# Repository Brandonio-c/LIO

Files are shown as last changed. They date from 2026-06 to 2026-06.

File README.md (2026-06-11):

<p align="center">
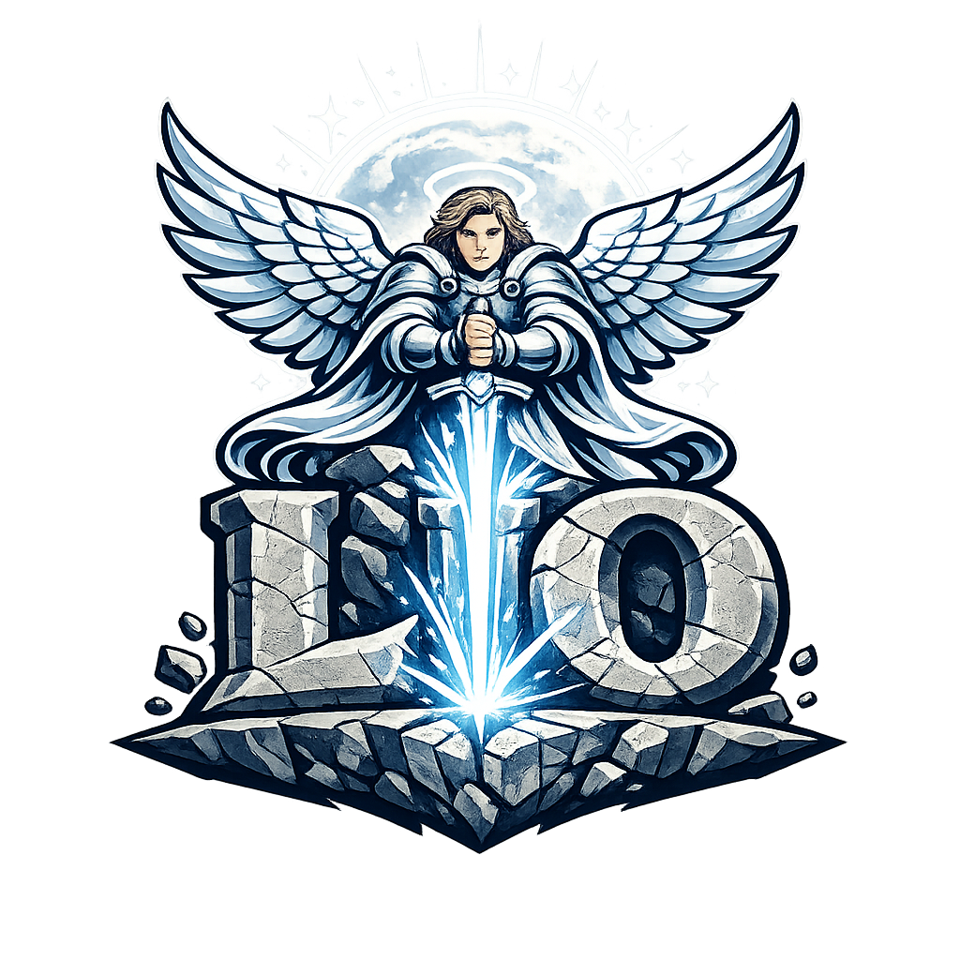
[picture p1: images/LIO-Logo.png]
LIO logo
  
</p>

**Lio** is an open hardware experiment to build a low-cost, 3D-printable multispectral diffuse-reflectance scanner for powdered food samples.

The project aims to collect repeatable optical reflectance data from controlled food powders and known mixtures using LED illumination, photodiode sensing, calibration references, and a motorized sample-height stage.

The core question LIO aims to answer is:

> Can a small, cheap, repeatable multispectral reflectance instrument produce enough signal to support useful closed-world food-powder classification or controlled-mixture experiments?

The honest answer is currently unknown. This repository documents the attempt.

---

## What Lio is trying to achieve

### Near-term goals

- Build a rigid, light-sealed optical chamber.
- Use one LED wavelength at a time to illuminate powdered samples.
- Measure reflected light using visible/NIR and SWIR detector paths.
- Normalize measurements using dark and PTFE white-reference readings.
- Create repeatable reflectance vectors for each sample.
- Validate mechanical repeatability before training any model.
- Test simple controlled mixtures before attempting complex packaged foods.

### Long-term goals

- Build a dataset of calibrated reflectance scans from known powders and mixtures.
- Compare simple models such as PCA, logistic regression, SVM, and PLS regression before trying neural networks.
- Evaluate whether additional SWIR wavelengths improve separability.
- Develop a closed-world composition-hypothesis workflow.
- Eventually detect whether unknown samples are optically consistent with trained known mixtures.

## Measurement concept

Lio uses **multispectral diffuse reflectance**.

A powdered sample sits in a controlled cup inside a dark, black-lined chamber. LEDs illuminate the sample one wavelength at a time. A detector measures reflected light from the sample. Each wavelength produces one channel value.

A scan sequence looks like this:

1. Record dark readings with all LEDs off.
2. Record white-reference readings using a PTFE reference insert.
3. Record sample readings using the food powder.
4. Normalize each channel:

```text
R_i = (S_i - D_i) / (W_i - D_i)
```

Where:

```text
R_i = normalized reflectance for wavelength i
S_i = sample reading
D_i = dark reading
W_i = white-reference reading
```

Optional absorbance-like transformation:

```text
A_i = -log10(R_i)
```

The output of one scan is a reflectance vector such as:

```text
[red, green, blue, 400, 890, 1020, 1200, 1300, 1450, 1550, 1650, 1760]
```

Exact channels depend on which LED modules are installed.

---

## Optical design

The optical system is built around a fixed top optical head and a moving bottom sample platform.

### Fixed optical section

- Top detector cap.
- Detector snout / aperture tube.
- LED ring with removable LED cartridges.
- Outer optical tube.
- Removable black flocked inner sleeve.
- Internal baffle rings.
- Bottom fixed collar / upper telescoping receiver.

### Moving sample section

- Moving sample platform.
- Powder sample cup.
- PTFE reference holder.
- Dark reference plug.
- Moving telescoping skirt / lower light-seal sleeve.

### Telescoping light-seal concept

The fixed optical chamber does not move. The sample platform moves up and down on a motorized Z-stage. A lower moving sleeve overlaps with an upper fixed collar so the optical path remains dark while the sample height changes.

```text
fixed optical tube
    ↓
bottom fixed collar / upper receiver
    ↓ overlaps with
moving telescoping skirt
    ↓ attached to
moving sample platform
    ↓ driven by
M6 threaded rod + 28BYJ motor
```

This is the physical mechanism referred to as the Lio telescoping focusing channel. It is not a lens. It is a light-sealed adjustable sample-height shroud.

---

## Mechanical architecture

The current mechanical architecture is a PETG 3D-printed tower with metal guide hardware.

### Motion system

- 28BYJ-48 5 V stepper motor.
- ULN2003 stepper driver board.
- M6 threaded rod as the vertical drive screw.
- M6 nut trapped in the moving platform.
- Two 8 mm guide rods.
- LM8UU linear bearings.
- Top guide bridge to keep rods parallel.
- Bottom motor base to hold rods, motor, screw, and endstop.
- Endstop switches for homing/safety.

### Coordinate logic

The mechanical drive axis and sample/optical axis are intentionally different:

```text
M6 drive axis:       X = 0, Y = 0
left guide rod:      X = -45, Y = 0
right guide rod:     X = +45, Y = 0
sample/optical axis: X = 0, Y = +35
```

The sample cup is offset forward so the M6 threaded rod does not pass through the sample.

The fixed tower frame holds the optical tube over the sample axis, not over the M6 drive axis.

---

## Electronics architecture

### Control and acquisition

- Arduino Nano or compatible controller
- ADS1115 16-bit I2C ADC modules
- One-LED-at-a-time sequencing
- Dark / white / sample scan workflow

### Detector paths

- OPT101 module for visible and shorter NIR channels
- InGaAs photodiode with an OPA381 transimpedance amplifier for SWIR channels

### LED control

- Individually addressable LED channels
- MOSFET or LED-driver switching
- A single channel active at any moment
- Optional current control / PWM dimming once baseline stability is established

### Motor control

- 28BYJ-48 stepper motor
- ULN2003 driver board
- External 5 V supply or power bank for motor power
- Shared ground between the motor supply and the Arduino

---

## CAD file set

The CAD is authored in OpenSCAD. Most files generate printable STL parts; one file is a non-printing assembly preview.

```text
01_lio_fit_tests.scad
02_lio_outer_tube.scad
03_lio_inner_sleeve.scad
04_lio_baffle_rings.scad
05_lio_detector_cap.scad
06_lio_led_ring.scad
07_lio_led_cartridges.scad
08_lio_bottom_collar.scad
09_lio_motor_base.scad
10_lio_top_guide_bridge.scad
11_lio_moving_platform.scad
12_lio_moving_telescoping_skirt.scad
13_lio_sample_accessories.scad
14_lio_electronics_tray.scad
15_lio_fixed_tower_frame.scad
16_lio_assembly_preview.scad
```

### 01 — Fit tests

Small validation prints for LM8UU bearing bores, M6 nut traps, M3 heat-set inserts, and 8 mm rod spacing. Print these before committing to large mechanical parts.

### 02 — Outer optical tube

The main fixed optical chamber body: 80 mm outer tube, 60 mm inner bore, top and bottom flanges, M3 insert bosses, an inner-sleeve alignment feature, and baffle-retaining ledges.

### 03 — Removable inner sleeve

A thin PETG cylinder that carries the black telescope flocking and lifts out for cleaning or optical adjustment.

### 04 — Baffle rings

Internal annular baffles that suppress glancing wall reflections and stray light.

### 05 — Detector cap

The top detector cap, with a PCB pocket, aperture, detector snout, and a wire-exit light-trap feature.

### 06 — LED ring

A 16-slot modular LED-ring body that accepts removable LED cartridges rather than fixing LED types permanently.

### 07 — LED cartridges

Wedge/cartridge inserts sized for 3 mm LEDs, 5 mm LEDs, SMD LEDs, and TO-can / metal-can emitters.

### 08 — Bottom collar / upper receiver

The fixed half of the telescoping light seal, mounted beneath the optical tube to receive and overlap the moving skirt.

### 09 — Motor base

The base of the Z-stage: 28BYJ motor mount, lower 8 mm guide-rod sockets, M6/coupler clearance, bottom endstop area, and an optional ULN2003 mount region.

### 10 — Top guide bridge

Anchors the top ends of the guide rods and provides upper M6 clearance and support.

### 11 — Moving platform

The sample carriage: LM8UU bearing housings, an M6 nut trap, a sample-cup pocket, an endstop flag, a height pointer, and mounting holes for the telescoping skirt.

### 12 — Moving telescoping skirt

The moving lower half of the telescoping light seal, mounted to the platform and overlapping the fixed receiver.

### 13 — Sample accessories

A batch of sample-prep and calibration parts: powder sample cup, PTFE reference holder, dark reference plug, and a leveling ring / scraper guide.

### 14 — Electronics tray

An open service tray for the Arduino, ADS1115 modules, ULN2003 board, USB pigtail strain relief, wire clips, and an LED cable comb.

### 15 — Fixed tower frame

The structural bridge between the stationary optical chamber and the motorized Z-stage. It holds the fixed optical tube/collar above the offset sample axis and turns the telescoping seal into a mechanically constrained assembly.

### 16 — Assembly preview

A non-printing OpenSCAD file that visualizes the full assembly. A `stage_z` parameter previews the platform at different heights. This file is for visualization only and is not sliced or printed.

---

## Recommended printing order

Mechanical geometry and fit tolerances take priority over the cosmetic optical shell, so print in this order:

```text
01 fit tests
09 motor base
10 top guide bridge
11 moving platform
12 moving telescoping skirt
15 fixed tower frame
08 bottom fixed collar
02 outer optical tube
03 inner sleeve
04 baffle rings
05 detector cap
06 LED ring
07 LED cartridges
13 sample accessories
14 electronics tray
16 assembly preview (visualization only)
```

---

## Print settings

Baseline settings for PETG on the Ender-3 V3 SE:

```text
Nozzle: 235–245 °C
Bed: 75–85 °C
Layer height: 0.20 mm
Walls: 4 for structural parts
Infill: 35–45% for mechanical parts
Supports: OFF where geometry is supportless
Brim: ON for tall/thin parts
First layer speed: 15–20 mm/s
Fan: low/off for first layers, then moderate
Bed prep: clean plate + thin glue-stick layer
```

Tall, thin parts such as the inner sleeve and baffle rings benefit from additional brim, sacrificial carrier strips, or shorter test prints.

---

## Data collection workflow

A complete scan session follows this sequence:

1. Home the Z-stage.
2. Set a known sample height.
3. Record a dark scan with LEDs off.
4. Insert the PTFE reference holder.
5. Record a white-reference scan.
6. Insert the sample cup.
7. Fire each LED one at a time.
8. Record detector readings.
9. Normalize using dark/white calibration.
10. Save raw and normalized data with metadata.

Each record carries metadata for full traceability:

```text
sample ID
batch ID
operator
timestamp
sample mass
sample cup depth
grind/sieve method
LED channel
LED current/PWM
detector used
TIA gain setting
ADC gain setting
sample height
temperature/humidity if available
white reference ID
firmware version
CAD revision
```

---

## Validation plan

Repeatability is verified before any modeling begins.

### Mechanical repeatability

- The Z-stage homes consistently.
- The platform moves smoothly without binding.
- The moving skirt overlaps the fixed receiver across all usable heights.
- The sample cup stays centered under the optical axis.

### Optical repeatability

- Dark readings hold steady over time.
- PTFE reference readings repeat across insert/remove cycles.
- A given powder yields repeatable normalized reflectance vectors.
- The chamber, wire exits, and telescoping sleeve stay light-tight.

### Dataset integrity

- Controlled binary mixtures precede complex packaged foods.
- Validation uses held-out batches and days.
- Repeated scans of the same physical sample are kept together rather than split across train and test sets.

---

## Modeling plan

Modeling starts with interpretable methods and adds complexity only as the data justifies it:

- PCA for visualization.
- Logistic regression, SVM, and random forest for classification.
- PLS regression for controlled concentration estimation.
- Neural networks introduced once enough independent, repeatable data exists to support them.

The first concrete targets are:

```text
Can Lio distinguish known powder classes under controlled preparation?
```

and:

```text
Can Lio estimate the percentage of one ingredient in a controlled binary mixture?
```

---

## Repository structure

```text
lio/
├── README.md
├── cad/
│   ├── 01_lio_fit_tests.scad
│   ├── 02_lio_outer_tube.scad
│   ├── 03_lio_inner_sleeve.scad
│   ├── 04_lio_baffle_rings.scad
│   ├── 05_lio_detector_cap.scad
│   ├── 06_lio_led_ring.scad
│   ├── 07_lio_led_cartridges.scad
│   ├── 08_lio_bottom_collar.scad
│   ├── 09_lio_motor_base.scad
│   ├── 10_lio_top_guide_bridge.scad
│   ├── 11_lio_moving_platform.scad
│   ├── 12_lio_moving_telescoping_skirt.scad
│   ├── 13_lio_sample_accessories.scad
│   ├── 14_lio_electronics_tray.scad
│   ├── 15_lio_fixed_tower_frame.scad
│   └── 16_lio_assembly_preview.scad
├── stl/
├── gcode/
├── firmware/
├── electronics/
├── data/
│   ├── raw/
│   ├── processed/
│   └── metadata/
├── notebooks/
├── docs/
└── photos/
```

---

## Current status

Lio is in early mechanical prototyping.

- Hardware components have been sourced.
- 3D-printer setup is underway.
- OpenSCAD files are evolving iteratively.
- The design now includes a fixed tower frame and assembly preview, which add the assembly constraints the original part list lacked.
- Current focus is mechanical fit and light sealing.
- Electronics and data collection follow once the physical platform is stable.

---

## Safety and operating notes

Lio is an experimental research prototype intended for controlled laboratory and educational use.

LEDs across the visible, UV, NIR, and SWIR ranges can deliver significant optical power, and some wavelengths are invisible while still being energetic. Handle the optics with appropriate care: avoid looking directly into LEDs, use current limiting, keep the optical path enclosed, and treat unknown high-power emitters with caution.

Results from Lio are research data. Keep them within the closed-world experimental context the instrument is built for.

---

## References

- Near-infrared spectroscopy in food quality assurance (review): https://www.mdpi.com/3022876
- NIST PTFE 45°/0° reflectance reference work: https://nvlpubs.nist.gov/nistpubs/jres/104/2/html/nad-k/nad.htm
- OpenSCAD documentation: https://openscad.org/documentation.html
- Creality Ender-3 V3 SE specifications: https://store.creality.com/products/ender-3-v3-se-3d-printer
- STL file format reference: https://www.xometry.com/resources/3d-printing/stl-file-format/

---

## License

A license has not yet been selected. Before the project opens to outside contributions, a license will be chosen deliberately. Candidate options include:

- MIT License for code
- CERN Open Hardware License for hardware/CAD
- Creative Commons license for documentation

---

## Project philosophy

Lio is an exercise in disciplined instrument design: build a controlled, repeatable measurement platform, collect clean data, and map out exactly what low-cost multispectral reflectance can do for closed-world food analysis. The work centers on repeatable measurements, well-characterized limits, and a clear, incremental path from mechanical validation to controlled-mixture discrimination and narrow classification.D_i = dark reading
W_i = white-reference reading
```

An optional absorbance-like transform is also available:

```text
A_i = -log10(R_i)
```

Each scan produces a reflectance vector, for example:

```text
[red, green, blue, 400, 890, 1020, 1200, 1300, 1450, 1550, 1650, 1760]
```

The exact channel set depends on which LED modules are installed.

---

## Optical design

The optical system pairs a fixed top optical head with a moving bottom sample platform.

### Fixed optical section

- Top detector cap
- Detector snout / aperture tube
- LED ring with removable LED cartridges
- Outer optical tube
- Removable black-flocked inner sleeve
- Internal baffle rings
- Bottom fixed collar / upper telescoping receiver

### Moving sample section

- Moving sample platform
- Powder sample cup
- PTFE reference holder
- Dark reference plug
- Moving telescoping skirt / lower light-seal sleeve

### Telescoping light seal

The optical chamber stays stationary while the sample platform travels vertically on a motorized Z-stage. A lower moving sleeve overlaps a fixed upper collar, keeping the optical path sealed against ambient light across the full range of sample heights.

```text
fixed optical tube
    ↓
bottom fixed collar / upper receiver
    ↓ overlaps with
moving telescoping skirt
    ↓ attached to
moving sample platform
    ↓ driven by
M6 threaded rod + 28BYJ motor
```

This mechanism is referred to as the Lio telescoping focusing channel: a light-sealed, adjustable sample-height shroud that maintains a dark optical path as the sample height changes.

---

## Mechanical architecture

The mechanical platform is a PETG 3D-printed tower built around metal guide hardware.

### Motion system

- 28BYJ-48 5 V stepper motor
- ULN2003 stepper driver board
- M6 threaded rod as the vertical drive screw
- M6 nut captured in the moving platform
- Two 8 mm guide rods
- LM8UU linear bearings
- Top guide bridge to keep the rods parallel
- Bottom motor base holding the rods, motor, screw, and endstop
- Endstop switches for homing and travel limits

### Coordinate logic

The mechanical drive axis and the sample/optical axis are intentionally separated:

```text
M6 drive axis:       X = 0, Y = 0
left guide rod:      X = -45, Y = 0
right guide rod:     X = +45, Y = 0
sample/optical axis: X = 0, Y = +35
```

Offsetting the sample cup forward keeps the M6 threaded rod clear of the sample. The fixed tower frame positions the optical tube direct# Lio

**Lio** is an open-hardware research instrument: a low-cost, 3D-printable multispectral diffuse-reflectance scanner for powdered food samples.

We are building a benchtop optical instrument that shines light through a sequence of individual LED wavelengths onto a prepared food powder, measures how much light each wavelength reflects back, and turns that into a calibrated spectral signature for the sample. By collecting these signatures across many known powders and controlled mixtures, we can train models that recognize what a sample is, or estimate how much of one ingredient is present in a blend. The entire instrument — optical chamber, motorized sample stage, electronics housing — is 3D-printable and built from inexpensive, widely available parts, so the whole design can be reproduced on a hobbyist printer for a fraction of the cost of a commercial spectrometer.

The work spans three layers that come together into a single platform:

- **Hardware** — a rigid, light-sealed optical chamber paired with a motorized Z-stage that raises and lowers the sample while keeping the optical path dark. LEDs illuminate one wavelength at a time; visible/NIR and SWIR detectors capture the reflected light.
- **Acquisition** — a calibrated scan workflow that normalizes every reading against dark and white references, producing repeatable reflectance vectors with full metadata for traceability.
- **Modeling** — a data pipeline that starts with interpretable methods (PCA, regression, SVM, PLS) to classify known powders and estimate controlled-mixture ratios, expanding toward more complex models as the dataset grows.

The scope is deliberately focused:

> A repeatable, closed-world optical data-collection platform for evaluating whether low-cost multispectral reflectance can classify known powdered foods and estimate changes in controlled mixtures.

---

## Motivation

Visible/NIR/SWIR spectroscopy is a well-established approach to food analysis. Near-infrared methods are widely deployed for rapid quality control, origin and authenticity screening, and broad compositional analysis, typically paired with chemometric calibration models. These techniques are indirect and calibration-driven by nature: the instrument measures reflected light, and a trained model maps that signal to a property of interest.

Lio brings that idea down to a hobbyist-accessible price point by replacing a full commercial spectrometer with a set of discrete, individually addressable LEDs. The central research question is straightforward:

> Can a small, inexpensive, repeatable multispectral reflectance instrument produce enough usable signal to support closed-world food-powder classification or controlled-mixture estimation?

This repository documents the design, build, and experimental program developed to answer that question.

---

## Objectives

### Near-term

- Build a rigid, light-sealed optical chamber.
- Illuminate powdered samples one LED wavelength at a time.
- Measure reflected light across visible/NIR and SWIR detector paths.
- Normalize every measurement against dark and PTFE white-reference readings.
- Produce repeatable reflectance vectors for each sample.
- Establish mechanical repeatability as a precondition for any modeling.
- Characterize simple controlled mixtures before moving to complex packaged foods.

### Long-term

- Assemble a calibrated dataset of reflectance scans from known powders and mixtures.
- Benchmark interpretable models (PCA, logistic regression, SVM, PLS regression) before exploring neural networks.
- Quantify how additional SWIR wavelengths affect class separability.
- Develop a closed-world composition-hypothesis workflow.
- Determine whether unknown samples are optically consistent with trained known mixtures.

---

## Scope

Lio is a research-grade instrument for controlled, closed-world experiments. It is purpose-built to:

- Acquire calibrated reflectance data from prepared powdered samples.
- Discriminate among a known, trained set of powder classes.
- Estimate mixture ratios within controlled binary systems.

Its design priority is measurement integrity: prove repeatability first, then controlled-mixture discrimination, then narrow closed-world classification. The instrument is intended for experimental and educational use rather than food-safety, medical, or regulatory applications.

---

## Measurement principle

Lio operates on **multispectral diffuse reflectance**.

A powdered sample sits in a controlled cup inside a dark, black-lined chamber. LEDs illuminate the sample one wavelength at a time, and a detector measures the diffusely reflected light. Each wavelength contributes one channel to the resulting spectral vector.

A scan sequence proceeds as follows:

1. Record dark readings with all LEDs off.
2. Record white-reference readings using a PTFE reference insert.
3. Record sample readings from the food powder.
4. Normalize each channel:

```text
R_i = (S_i - D_i) / (W_i - D_i)
```

Where:

```text
R_i = normalized reflectance for wavelength i
S_i = sample reading
D_i = dark reading
W_i = white

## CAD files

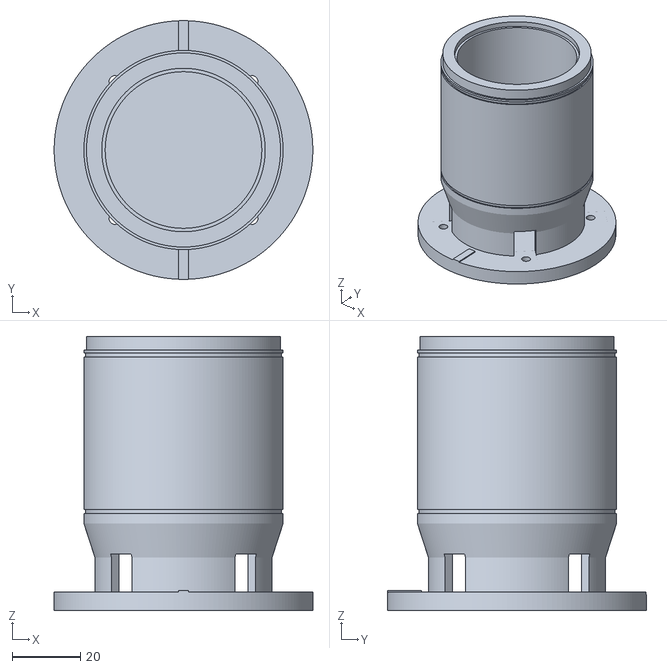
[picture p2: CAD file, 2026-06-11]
CAD/013-LIO-3D-print_moving_telescoping_skirt_v01.stl
76.0 x 76.0 x 80.5

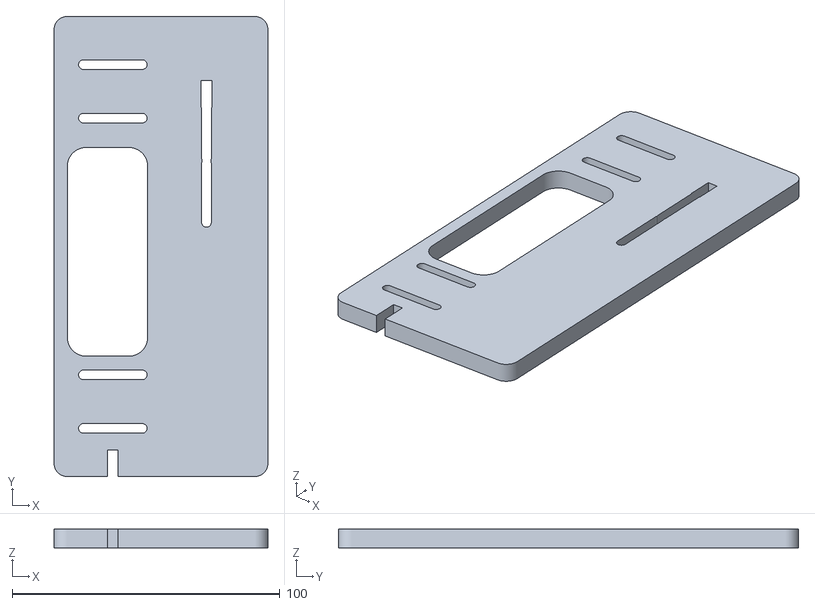
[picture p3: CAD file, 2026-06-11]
CAD/15_lio_fixed_tower_frame_v01.stl
80.0 x 172.0 x 7.00

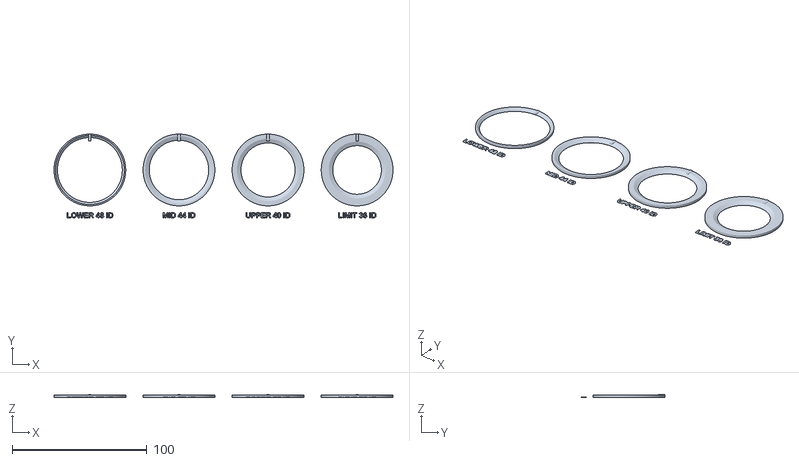
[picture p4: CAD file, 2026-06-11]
CAD/005-LIO-3D-print_baffle_ring_set_v01.stl
251.2 x 62.1 x 2.40

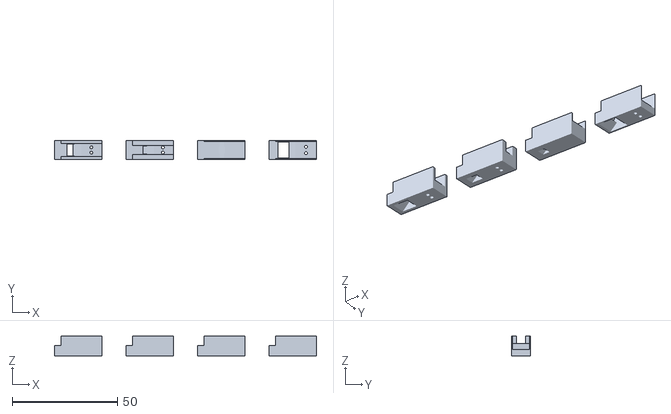
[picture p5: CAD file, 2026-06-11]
CAD/008-LIO-3D-print_led_cartridge_wedge_set_v02_SUPPORTLESS.stl
124.5 x 8.80 x 9.40

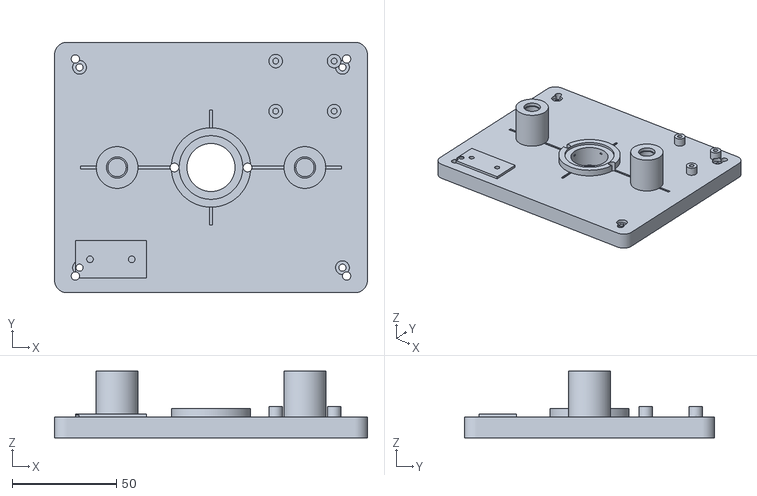
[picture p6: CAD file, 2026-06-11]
CAD/010-LIO-3D-print_motor_base_v01.stl
150.0 x 120.0 x 32.0

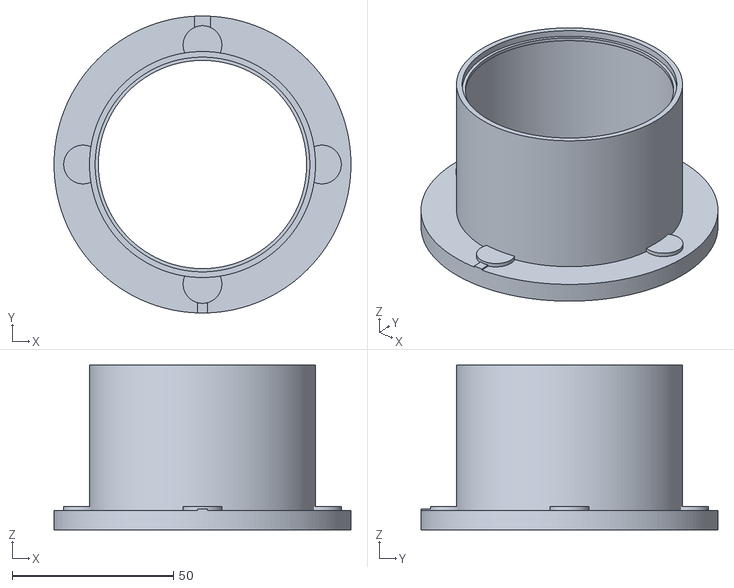
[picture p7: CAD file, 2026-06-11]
CAD/009-LIO-3D-print_bottom_fixed_collar_v01.stl
92.0 x 92.0 x 51.0

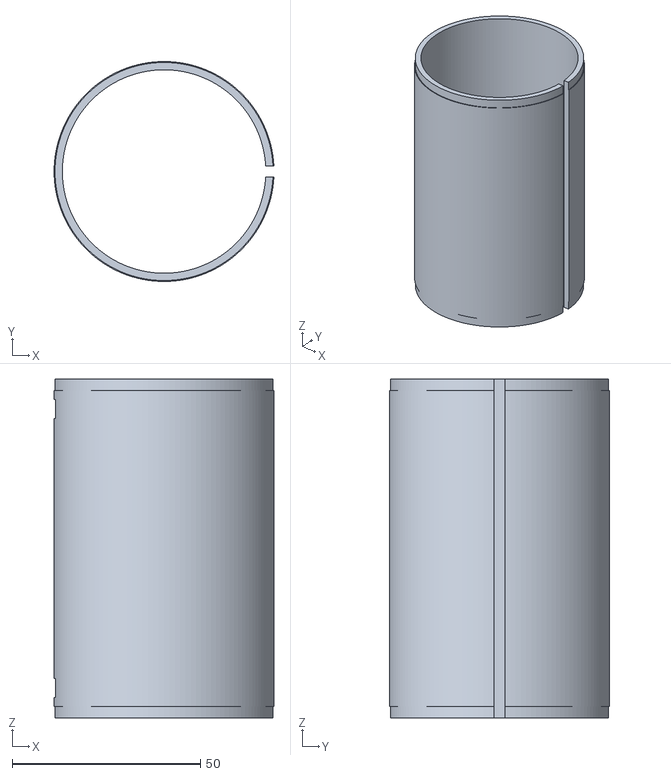
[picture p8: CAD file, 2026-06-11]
CAD/004-LIO-3D-print_inner_sleeve_v01.stl
58.4 x 58.4 x 90.0

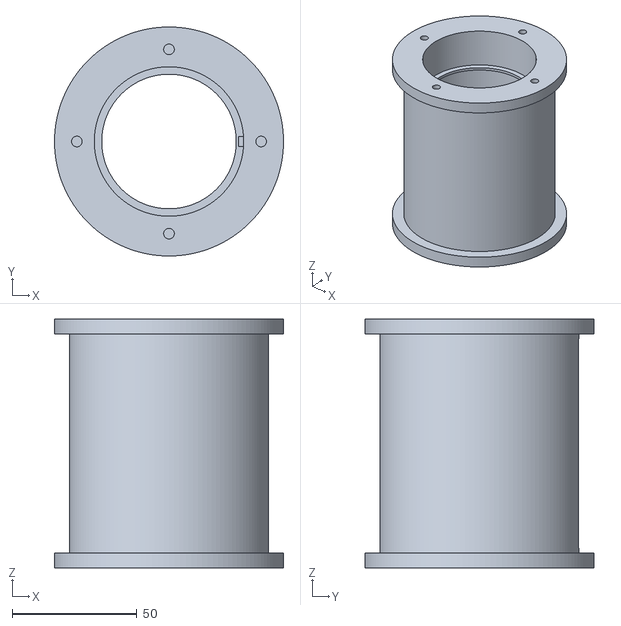
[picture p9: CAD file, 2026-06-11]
CAD/003-LIO-3D-print_outer_optical_tube_v01.stl
92.0 x 92.0 x 100.0

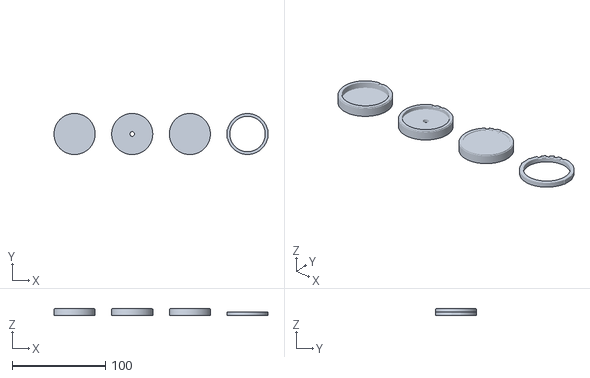
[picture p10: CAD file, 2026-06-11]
CAD/014-LIO-3D-print_sample_accessory_batch_v01.stl
230.1 x 44.2 x 8.00

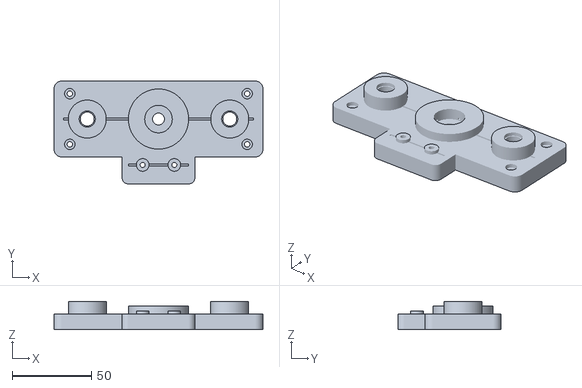
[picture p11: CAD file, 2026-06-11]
CAD/011-LIO-3D-print_top_guide_bridge_v02.stl
132.0 x 65.0 x 18.0

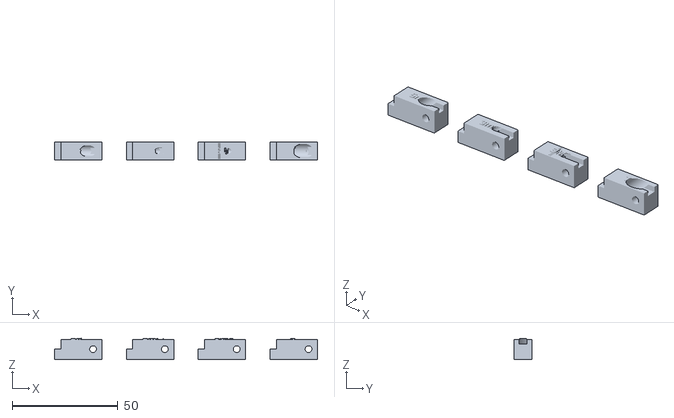
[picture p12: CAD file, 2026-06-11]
CAD/008-LIO-3D-print_led_cartridge_wedge_set_v01.stl
124.5 x 8.60 x 10.1

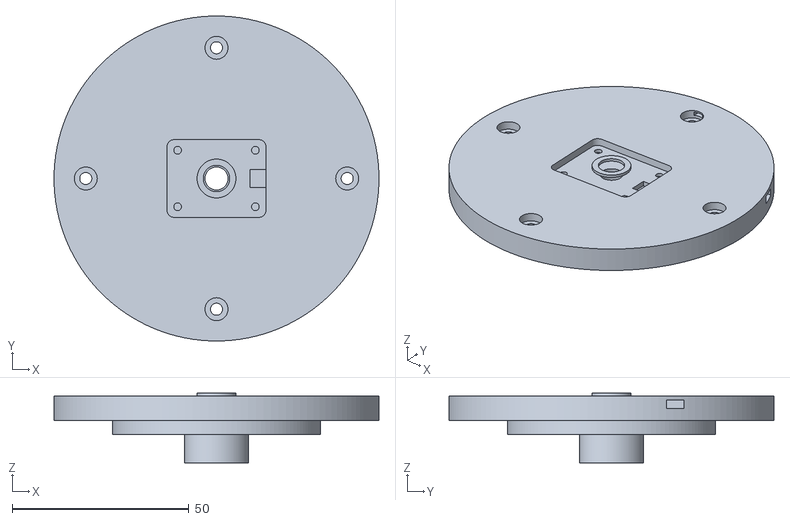
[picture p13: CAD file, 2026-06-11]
CAD/006-LIO-3D-print_detector_cap_OPT101_v01.stl
92.0 x 92.0 x 19.8

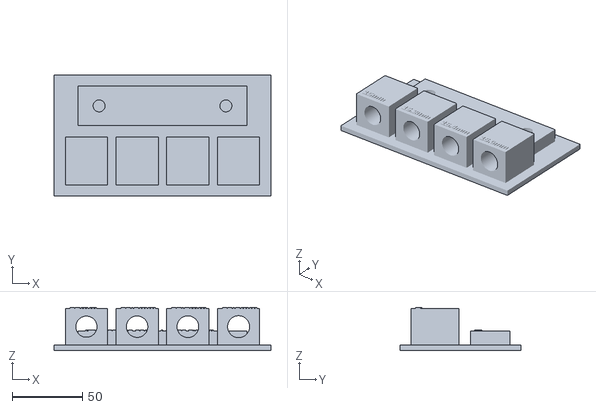
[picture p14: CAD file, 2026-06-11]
CAD/001-LIO-3D-print_test-parts.stl
154.0 x 86.0 x 30.7

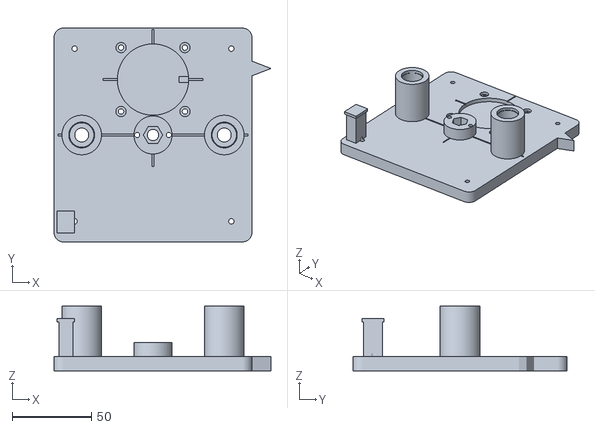
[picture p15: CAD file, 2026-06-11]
CAD/012-LIO-3D-print_moving_sample_platform_v01.stl
137.0 x 135.0 x 41.0

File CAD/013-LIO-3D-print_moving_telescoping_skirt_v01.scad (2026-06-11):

// Lio v0.1 — Moving Telescoping Skirt / Lower Light-Seal Sleeve
// Units: millimeters
//
// This part integrates:
// - moving half of telescoping optical shroud
// - sample cup opening / optical path opening
// - flocking carrier sleeve
// - mounting flange to moving sample platform
//
// Physical role:
// - Mounts to the moving sample platform around the sample cup.
// - Moves up/down with the sample.
// - Slides into / overlaps with the fixed bottom collar receiver.
// - Preserves a dark optical path while the Z-stage moves.
//
// PRINT ORIENTATION:
// - Flange flat on bed at Z=0.
// - Sleeve prints upward.
// - Supports OFF.
//
// Material:
// - Black PETG recommended.
//
// Suggested print settings:
// - 0.20 mm layer height
// - 3–4 walls
// - 25–35% infill
// - supports OFF
// - brim optional

$fn = 160;
eps = 0.05;

// ---------------------------------------------------------
// Main skirt geometry
// ---------------------------------------------------------

// Main upper sleeve outer diameter.
// This slides into the fixed bottom collar receiver.
// Fixed collar receiver ID was about 64.5 mm,
// so 58.5 mm gives generous clearance for flocking and imperfect rods.
sleeve_od = 58.5;

// Inner optical/sample opening.
// 44–50 mm recommended.
// Use 46 mm as a sane v0.1 balance.
sleeve_id = 46.0;

// Total sleeve region above flange is:
// lower neck + tapered transition + main sleeve
lower_neck_od = 52.0;      // clears M3 mount holes better than full 58.5 OD
lower_neck_h  = 10.0;

transition_h = 10.0;       // tapered section from lower neck to full sleeve OD
main_sleeve_h = 55.0;      // straight upper sleeve height

total_sleeve_h = lower_neck_h + transition_h + main_sleeve_h;

// ---------------------------------------------------------
// Mounting flange geometry
// ---------------------------------------------------------

flange_od = 76.0;
flange_t  = 5.5;

// Must match moving platform skirt_mount_bcd = 57 from Print 12.
mount_bcd = 57.0;
mount_r = mount_bcd / 2;

m3_clearance_d = 3.4;

// No screw-head recess by default.
// Recesses would collide with the lower neck at this compact bolt circle.
enable_screw_head_recess = false;
m3_head_recess_d = 6.5;
m3_head_recess_depth = 2.0;

// Screw access notches cut into the lower neck so you can physically
// reach the M3 screws even though the sleeve is close to the bolt circle.
enable_screw_access_notches = true;
screw_access_radial_len = 12.0;
screw_access_tangent_w = 8.5;
screw_access_h = lower_neck_h + 1.0;

// ---------------------------------------------------------
// Flocking / liner features
// ---------------------------------------------------------

// Outer shallow grooves help locate/catch the edge of external flocking,
// if you decide to flock the outside of the moving skirt.
// Keep these shallow so the skirt remains strong.
enable_flocking_edge_grooves = true;
flocking_groove_depth = 0.5;
flocking_groove_h = 1.2;

// Position grooves near lower and upper areas of the main sleeve.
flocking_lower_groove_z = flange_t + lower_neck_h + transition_h + 3;
flocking_upper_groove_z = flange_t + total_sleeve_h - 6;

// ---------------------------------------------------------
// Lead-in / anti-scrape features
// ---------------------------------------------------------

// Slightly reduce OD at very top so it enters the fixed receiver more easily.
enable_top_leadin = true;
top_leadin_h = 4.0;
top_leadin_od_reduction = 1.5;

// Slight inner mouth bevel/relief.
// This is a straight relief, not a true curved chamfer.
enable_inner_mouth_relief = true;
inner_mouth_relief_d = sleeve_id + 2.0;
inner_mouth_relief_h = 2.0;

// ---------------------------------------------------------
// Optional alignment mark
// ---------------------------------------------------------

enable_alignment_mark = true;
alignment_mark_w = 3.0;
alignment_mark_l = 9.0;
alignment_mark_depth = 0.8;

// ---------------------------------------------------------
// Helper modules
// ---------------------------------------------------------

module ring(od, id, h) {
    difference() {
        cylinder(d = od, h = h);
        translate([0, 0, -1])
            cylinder(d = id, h = h + 2);
    }
}

module tapered_ring(od1, od2, id, h) {
    difference() {
        cylinder(d1 = od1, d2 = od2, h = h);
        translate([0, 0, -1])
            cylinder(d = id, h = h + 2);
    }
}

module mount_holes_cut() {
    for (a = [45, 135, 225, 315]) {
        rotate([0, 0, a])
        translate([mount_r, 0, -1]) {
            cylinder(d = m3_clearance_d, h = flange_t + 2);

            if (enable_screw_head_recess) {
                translate([0, 0, flange_t - m3_head_recess_depth])
                    cylinder(d = m3_head_recess_d,
                             h = m3_head_recess_depth + 1);
            }
        }
    }
}

module screw_access_notches_cut() {
    if (enable_screw_access_notches) {
        for (a = [45, 135, 225, 315]) {
            rotate([0, 0, a])
            translate([
                mount_r,
                0,
                flange_t + screw_access_h/2
            ])
                cube([
                    screw_access_radial_len,
                    screw_access_tangent_w,
                    screw_access_h + 2*eps
                ], center = true);
        }
    }
}

module flocking_edge_groove_cut(zpos) {
    if (enable_flocking_edge_grooves) {
        // Shallow external annular groove.
        // Cuts only the outside surface of the upper sleeve.
        translate([0, 0, zpos])
        difference() {
            cylinder(d = sleeve_od + 2, h = flocking_groove_h);
            translate([0, 0, -eps])
                cylinder(d = sleeve_od - 2*flocking_groove_depth,
                         h = flocking_groove_h + 2*eps);
        }
    }
}

module top_leadin_cut() {
    if (enable_top_leadin) {
        // Remove a shallow outer band at the very top,
        // reducing OD slightly for easier entry into fixed collar receiver.
        translate([0, 0, flange_t + total_sleeve_h - top_leadin_h])
        difference() {
            cylinder(d = sleeve_od + 2, h = top_leadin_h + eps);
            translate([0, 0, -eps])
                cylinder(d = sleeve_od - top_leadin_od_reduction,
                         h = top_leadin_h + 2*eps);
        }
    }
}

module inner_mouth_relief_cuts() {
    if (enable_inner_mouth_relief) {
        // Relief at top inner opening.
        translate([0, 0, flange_t + total_sleeve_h - inner_mouth_relief_h])
            cylinder(d = inner_mouth_relief_d,
                     h = inner_mouth_relief_h + eps);

        // Relief at bottom inner opening / flange entry.
        translate([0, 0, -eps])
            cylinder(d = inner_mouth_relief_d,
                     h = inner_mouth_relief_h + eps);
    }
}

module alignment_mark_cut() {
    if (enable_alignment_mark) {
        // Shallow notch on flange outer edge at +Y.
        translate([
            0,
            flange_od/2 - alignment_mark_l/2,
            flange_t - alignment_mark_depth/2 + eps
        ])
            cube([
                alignment_mark_w,
                alignment_mark_l,
                alignment_mark_depth + 2*eps
            ], center = true);
    }
}

// ---------------------------------------------------------
// Main model
// ---------------------------------------------------------

difference() {

    union() {

        // Bottom mounting flange.
        cylinder(d = flange_od, h = flange_t);

        // Lower neck. Smaller OD clears mounting screws.
        translate([0, 0, flange_t])
            ring(lower_neck_od, sleeve_id, lower_neck_h);

        // Sloped transition out to full telescoping sleeve OD.
        // Supportless because it is a gradual outward taper.
        translate([0, 0, flange_t + lower_neck_h])
            tapered_ring(
                od1 = lower_neck_od,
                od2 = sleeve_od,
                id = sleeve_id,
                h = transition_h
            );

        // Main moving telescoping sleeve.
        translate([0, 0, flange_t + lower_neck_h + transition_h])
            ring(sleeve_od, sleeve_id, main_sleeve_h);
    }

    // Mounting holes matching Print 12 moving platform.
    mount_holes_cut();

    // Access notches around lower neck for screw access.
    screw_access_notches_cut();

    // External flocking edge grooves.
    flocking_edge_groove_cut(flocking_lower_groove_z);
    flocking_edge_groove_cut(flocking_upper_groove_z);

    // Top lead-in relief.
    top_leadin_cut();

    // Inner mouth reliefs.
    inner_mouth_relief_cuts();

    // Alignment notch.
    alignment_mark_cut();
}

// ---------------------------------------------------------
// Optional small raised orientation marker opposite notch
// ---------------------------------------------------------

marker_h = 0.8;
marker_w = 3.0;
marker_l = 10.0;
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

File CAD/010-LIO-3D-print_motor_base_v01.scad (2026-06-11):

    // Lio v0.1 — Motor Base with Integrated 28BYJ Mount and Lower Rod Sockets
// Units: millimeters
//
// This part integrates:
// - base plate
// - 28BYJ-48 motor mount / alignment pocket
// - lower 8 mm guide rod sockets
// - M6 threaded rod / coupler clearance
// - optional ULN2003 driver board mount
// - bottom endstop mounting zone
// - feet/riser holes
// - M3 holes for attaching later frame/electronics components
//
// Physical role:
// - Keeps the motor, M6 screw, and two 8 mm guide rods aligned.
// - Provides the mechanical foundation for the Lio motorized Z-stage.
//
// IMPORTANT ASSEMBLY NOTE:
// - This v0.1 base assumes the 28BYJ-48 is mounted on the TOP SIDE
//   of the base, centered under the M6 threaded rod.
// - The motor shaft points upward into the coupler.
// - If your exact 28BYJ-48 body/mount geometry differs, measure it
//   and adjust motor_* parameters below.
//
// Print orientation:
// - Flat on bed.
// - Supports OFF.
//
// Material:
// - PETG recommended.
//
// Suggested print settings:
// - 0.20 mm layer height
// - 4 walls
// - 35–45% infill
// - supports OFF
// - brim optional

$fn = 128;
eps = 0.05;

// ---------------------------------------------------------
// Main base dimensions
// ---------------------------------------------------------

base_w = 150;        // suggested 130–150 mm
base_d = 120;        // suggested 100–130 mm
base_t = 10;         // suggested 8–12 mm
base_corner_r = 6;

// ---------------------------------------------------------
// Guide rod sockets
// ---------------------------------------------------------

rod_spacing = 90;        // center-to-center spacing between 8 mm guide rods
rod_x = rod_spacing / 2;

rod_socket_od = 20;      // outside diameter of printed rod socket tower
rod_socket_h  = 22;      // tower height above base
rod_socket_d  = 8.8;     // hole diameter for 8 mm rods; increase if your rods bind
rod_socket_depth = 18;   // blind socket depth; should be 10–20 mm

// Optional larger lead-in at the top of rod socket.
rod_socket_leadin_d = 10.2;
rod_socket_leadin_h = 2.0;

// ---------------------------------------------------------
// M6 threaded rod / shaft coupler clearance
// ---------------------------------------------------------

// Your M6 threaded rod sits on the centerline.
// The 5mm-to-6mm coupler is usually ~20 mm OD,
// so this clearance hole gives space around it.
coupler_clearance_d = 23.0;
m6_rod_clearance_d  = 7.2;

// Raised circular boss around coupler zone.
center_boss_d = 38;
center_boss_h = 4;

// ---------------------------------------------------------
// 28BYJ-48 motor mount
// ---------------------------------------------------------

// Common 28BYJ-48 values:
// - body diameter around 28 mm
// - shaft diameter around 5 mm
// - mounting hole spacing around 35 mm
//
// This mount uses a shallow circular alignment pocket and two vertical
// mounting holes. The pocket is open from the top, so it prints support-free.

motor_body_pocket_d = 30.5;   // shallow top pocket for motor face/body alignment
motor_pocket_depth  = 1.4;

motor_mount_spacing = 35.0;   // distance between mounting holes
motor_mount_hole_d  = 4.2;    // 28BYJ tabs often have ~4.2 mm holes; use washer if using M3

// Pocket orientation:
// motor tabs along X axis by default.
motor_mount_axis_angle = 0;

// ---------------------------------------------------------
// Frame / optical tube attachment holes
// ---------------------------------------------------------

// These are generic M3 clearance holes for future side brackets,
// tube supports, electronics tray brackets, etc.
frame_hole_d = 3.4;
frame_hole_x = 63;
frame_hole_y = 48;

// Optional head recesses on top of frame holes.
enable_frame_hole_recess = true;
frame_recess_d = 6.6;
frame_recess_depth = 2.0;

// ---------------------------------------------------------
// Bottom endstop mounting zone
// ---------------------------------------------------------

enable_endstop_mount = true;

// A small raised pad near the front-left side.
// Most cheap endstop modules have varying hole spacing;
// this gives two M3 vertical holes spaced 20 mm apart.
endstop_pad_w = 34;
endstop_pad_d = 18;
endstop_pad_h = 3;
endstop_pad_x = -48;
endstop_pad_y = -44;

endstop_hole_spacing = 20;
endstop_hole_d = 3.2;

// ---------------------------------------------------------
// Optional ULN2003 driver board mount
// ---------------------------------------------------------

enable_uln2003_mount = true;

// Common ULN2003 boards vary around 31–35 mm.
// This is a generic 4-standoff pattern.
uln_center_x = 45;
uln_center_y = 39;

uln_standoff_spacing_x = 28;
uln_standoff_spacing_y = 24;
uln_standoff_d = 6.5;
uln_standoff_h = 5.0;
uln_hole_d = 2.8;       // use M2.5/M3 self-tap/pilot; widen if needed

// ---------------------------------------------------------
// Feet / riser holes
// ---------------------------------------------------------

enable_feet_holes = true;
foot_hole_d = 4.0;
foot_x = 65;
foot_y = 52;

// ---------------------------------------------------------
// Optional alignment marks
// ---------------------------------------------------------

enable_shallow_alignment_marks = true;
mark_depth = 0.8;

// ---------------------------------------------------------
// Helper modules
// ---------------------------------------------------------

module rounded_plate(w, d, h, r) {
    hull() {
        for (x = [-w/2 + r, w/2 - r])
        for (y = [-d/2 + r, d/2 - r])
            translate([x, y, 0])
                cylinder(r = r, h = h);
    }
}

module rod_socket_tower(xpos) {
    translate([xpos, 0, base_t])
        cylinder(d = rod_socket_od, h = rod_socket_h);
}

module rod_socket_hole_cut(xpos) {
    // Blind vertical hole from top of socket tower downward.
    translate([
        xpos,
        0,
        base_t + rod_socket_h - rod_socket_depth
    ])
        cylinder(d = rod_socket_d, h = rod_socket_depth + eps);

    // Larger lead-in chamfer/relief at top.
    translate([
        xpos,
        0,
        base_t + rod_socket_h - rod_socket_leadin_h
    ])
        cylinder(d = rod_socket_leadin_d, h = rod_socket_leadin_h + eps);
}

module center_boss() {
    translate([0, 0, base_t])
        cylinder(d = center_boss_d, h = center_boss_h);
}

module center_clearance_cuts() {
    // Through-hole for coupler/motor shaft/M6 rod axis.
    translate([0, 0, -1])
        cylinder(d = coupler_clearance_d, h = base_t + center_boss_h + 3);

    // Optional smaller center guide hole reference is not used because
    // coupler clearance dominates.
}

module motor_alignment_pocket_cut() {
    // Shallow open-top pocket. No support needed.
    translate([0, 0, base_t + center_boss_h - motor_pocket_depth])
        cylinder(d = motor_body_pocket_d, h = motor_pocket_depth + eps);
}

module motor_mount_holes_cut() {
    // Two vertical holes for 28BYJ-48 mounting tabs.
    rotate([0, 0, motor_mount_axis_angle]) {
        for (x = [-motor_mount_spacing/2, motor_mount_spacing/2]) {
            translate([x, 0, -1])
                cylinder(d = motor_mount_hole_d,
                         h = base_t + center_boss_h + 3);
        }
    }
}

module frame_mount_holes_cut() {
    for (x = [-frame_hole_x, frame_hole_x])
    for (y = [-frame_hole_y, frame_hole_y]) {
        translate([x, y, -1])
            cylinder(d = frame_hole_d, h = base_t + 3);

        if (enable_frame_hole_recess) {
            translate([x, y, base_t - frame_recess_depth])
                cylinder(d = frame_recess_d, h = frame_recess_depth + 1);
        }
    }
}

module feet_holes_cut() {
    if (enable_feet_holes) {
        for (x = [-foot_x, foot_x])
        for (y = [-foot_y, foot_y]) {
            translate([x, y, -1])
                cylinder(d = foot_hole_d, h = base_t + 3);
        }
    }
}

module endstop_pad() {
    if (enable_endstop_mount) {
        translate([endstop_pad_x, endstop_pad_y, base_t])
            cube([endstop_pad_w, endstop_pad_d, endstop_pad_h], center = true);
    }
}

module endstop_holes_cut() {
    if (enable_endstop_mount) {
        for (x = [-endstop_hole_spacing/2, endstop_hole_spacing/2]) {
            translate([
                endstop_pad_x + x,
                endstop_pad_y,
                base_t - 1
            ])
                cylinder(d = endstop_hole_d,
                         h = endstop_pad_h + 3);
        }
    }
}

module uln2003_standoffs() {
    if (enable_uln2003_mount) {
        for (x = [-uln_standoff_spacing_x/2, uln_standoff_spacing_x/2])
        for (y = [-uln_standoff_spacing_y/2, uln_standoff_spacing_y/2]) {
            translate([
                uln_center_x + x,
                uln_center_y + y,
                base_t
            ])
                cylinder(d = uln_standoff_d, h = uln_standoff_h);
        }
    }
}
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

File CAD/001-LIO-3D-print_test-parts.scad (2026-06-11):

// Lio v0.1 — LM8UU bearing bore + 8 mm rod spacing test block
// Units: millimeters
//
// Purpose:
// 1. Test LM8UU bearing bore fit with 15.0, 15.2, 15.4, 15.6 mm horizontal tunnels.
// 2. Test two 8 mm guide rods through vertical 8.5 mm holes spaced 90 mm apart.
// 3. Print flat on the bed.
//
// After printing:
// - Try sliding/pressing an LM8UU bearing into each horizontal tunnel.
// - The best tunnel is snug but not destructive.
// - Slide your two 8 mm rods through the vertical holes to check spacing/alignment.

$fn = 96;

// ----------------------
// Main parameters
// ----------------------

// Bearing test block parameters
bearing_hole_diameters = [15.0, 15.2, 15.4, 15.6];

block_w = 30;          // width of each bearing test block along X
block_d = 34;          // depth along Y; must exceed LM8UU length enough to grip/check fit
block_h = 26;          // height along Z; must exceed bearing OD
block_gap = 6;         // gap between bearing blocks

bearing_axis_z = block_h / 2;
bearing_axis_y = 0;

// Base plate parameters
base_margin_x = 8;
base_margin_y = 8;
base_t = 4;

// Rod spacing bridge
rod_spacing = 90;      // center-to-center spacing between 8 mm guide rods
rod_hole_d = 8.5;      // clearance for 8 mm rods; change to 8.4 or 8.6 if needed
rod_bridge_w = 120;
rod_bridge_d = 28;
rod_bridge_h = 10;

// Text label settings
label_size = 5;
label_depth = 0.7;

// Derived dimensions
num_blocks = len(bearing_hole_diameters);
total_blocks_w = num_blocks * block_w + (num_blocks - 1) * block_gap;
base_w = max(total_blocks_w + 2 * base_margin_x, rod_bridge_w + 2 * base_margin_x);
base_d = block_d + rod_bridge_d + 3 * base_margin_y;

// Place bearing blocks toward front, rod bridge toward back
bearing_row_y = -base_d/2 + base_margin_y + block_d/2;
rod_bridge_y  =  base_d/2 - base_margin_y - rod_bridge_d/2;

// ----------------------
// Helper modules
// ----------------------

module bearing_test_block(hole_d, label_text) {
    difference() {
        // Solid block
        cube([block_w, block_d, block_h], center = true);

        // Horizontal bearing tunnel through Y axis
        translate([0, 0, bearing_axis_z - block_h/2])
        rotate([90, 0, 0])
            cylinder(d = hole_d, h = block_d + 4, center = true);

        // Small bottom relief so bridging is not too ugly
        // Optional; comment out if you want a fully round tunnel.
        // translate([0, 0, 0])
        // cube([hole_d * 0.65, block_d + 5, hole_d * 0.25], center = true);
    }

    // Raised label on top
    translate([-block_w/2 + 3, -block_d/2 + 3, block_h/2])
        linear_extrude(height = label_depth)
            text(label_text, size = label_size, font = "Liberation Sans:style=Bold");
}

module rod_spacing_bridge() {
    difference() {
        cube([rod_bridge_w, rod_bridge_d, rod_bridge_h], center = true);

        // Two vertical holes for 8 mm guide rods
        for (x = [-rod_spacing/2, rod_spacing/2]) {
            translate([x, 0, -rod_bridge_h/2 - 1])
                cylinder(d = rod_hole_d, h = rod_bridge_h + 2);
        }
    }

    // Raised label
    translate([-rod_bridge_w/2 + 5, -rod_bridge_d/2 + 4, rod_bridge_h/2])
        linear_extrude(height = label_depth)
            text(str("Rod spacing ", rod_spacing, "mm / holes ", rod_hole_d, "mm"),
                 size = 4.2,
                 font = "Liberation Sans:style=Bold");
}

// ----------------------
// Full combined part
// ----------------------

union() {
    // Base plate connecting all features
    translate([0, 0, base_t/2])
        cube([base_w, base_d, base_t], center = true);

    // Four bearing test blocks
    for (i = [0 : num_blocks - 1]) {
        x_pos = -total_blocks_w/2 + block_w/2 + i * (block_w + block_gap);
        hole_d = bearing_hole_diameters[i];

        translate([x_pos, bearing_row_y, base_t + block_h/2])
            bearing_test_block(hole_d, str(hole_d, "mm"));
    }

    // Rod spacing bridge
    translate([0, rod_bridge_y, base_t + rod_bridge_h/2])
        rod_spacing_bridge();
}

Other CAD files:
CAD/creality_print_files/LIO-3D-print_test-parts_PLA_3h12m.gcode.3mf
CAD/015-LIO-3D-print_electronics_tray_v01.stl
CAD/007-LIO-3D-print_led-ring-body_v02_SUPPORTLESS.stl
CAD/007-LIO-3D-print_led-ring-body_v01.stl
CAD/002-LIO-3D-print_test-parts_2-nut_tests.scad
CAD/003-LIO-3D-print_outer_optical_tube_v01.scad
CAD/004-LIO-3D-print_inner_sleeve_v01.scad
CAD/005-LIO-3D-print_baffle_ring_set_v01.scad
CAD/006-LIO-3D-print_detector_cap_OPT101_v01.scad
CAD/006-LIO-3D-print_detector_cap_OPT101_v02_supportlessscad.scad
CAD/006-LIO-3D-print_detector_cap_OPT101_v02_supportlessscad.stl
CAD/007-LIO-3D-print_led-ring-body_v01.scad
CAD/007-LIO-3D-print_led-ring-body_v02_SUPPORTLESS.scad
CAD/008-LIO-3D-print_led_cartridge_wedge_set_v01.scad
CAD/008-LIO-3D-print_led_cartridge_wedge_set_v02_SUPPORTLESS.scad
CAD/009-LIO-3D-print_bottom_fixed_collar_v01.scad
CAD/011-LIO-3D-print_top_guide_bridge_v01.scad
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

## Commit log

2026-06-11 initial upload
    [001-LIO-3D-print_test-parts.scad, 001-LIO-3D-print_test-parts.stl, 002-LIO-3D-print_test-parts_2-nut_tests.scad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]
2026-11-03 Add LIO V3 electronics Rev A: schematic, technical document LIO-ELEC-001, BOM/netlist, firmware, logger, project docs, dual-detector plate, V2/V3 CAD
2026-11-03 firmware: preserve TEST_MODE and motor-control sketches as legacy
    - legacy/lio_firmware_testmode: unchanged copy of the Rev A TEST_MODE
    firmware (renamed to match its sketch folder)
    - legacy/lio_motor_control: the AccelStepper sketch used by
    lio_control.py, unchanged apart from a do-not-flash header (D10
    pull-up vs CE2, 595s never cleared, unbounded jogs)
2026-11-03 firmware: v2 command-driven firmware (protocol 1)
    Replaces the compile-time TEST_MODE sketch (kept in legacy/ and tag
    fw-testmode-v1) with a line-based command protocol:
    PING INFO STATUS I2C ADC SR CE CH OFF MEAS SWEEP LOOP MOTOR WDT RESET,
    plus the bounded legacy jog layer for lio_control.py
    (U D LU LD RU RD S VA VS ACC POSL0 POSR0 ?).
    Safety enforced in firmware:
    - power-up dark state first in setup(): CE1/CE2 low, 595s cleared
    - one-channel invariant; select MOSFET before CE, CE low before reselect
    - per-rail on-time watchdog (A 2 s / cap 5 s, B 5 s / cap 10 s)
    - 10 s comms-loss failsafe: LEDs off, motors stopped, disarmed
    - MOTOR STEP only when armed (token from INFO, 60 s), <= 2048 hal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
2026-11-03 firmware(legacy): document motor-sketch self-start on current wiring
    The UP-button input on D10 (now CE2 with a 10 k pull-down) reads as
    pressed, so the sketch starts an unbounded synchronized UP move ~30 ms
    after every reset. Observed during the M0.5 listen-only check.
2026-11-03 docs: firmware v2 serial protocol reference (PROTOCOL.md)
    Framing, OK/ERR/# grammar, error codes, every command with its
    response fields, firmware safety rules, the legacy jog exception to
    the arming rule (approved in M0), timing, and build/flash steps for
    both Nano bootloaders. Documents the ADC STREAM LED schedule added
    for T07.1.
2026-11-03 ci: lint and firmware compile with SRAM <= 75% gate
    Compiles firmware v2 for both Nano bootloader variants and the
    hardware-watchdog build, plus the legacy TEST_MODE sketch, with
    pinned core/library versions. tools/firmware_size_gate.py parses
    arduino-cli JSON output and writes sizes to the job summary.
2026-11-03 config: lio_hw.yaml hardware description and provisional thresholds
    Single source for pin map, channel map (hole -> wavelength, rail,
    per-detector expectation, fitted), ADC/detector constants, firmware
    limits mirrored from config.h, LED duty budget, run metadata
    (sample_id required, default none-empty-chamber), provisional test
    thresholds (plan §5.4) and simulator physics parameters.
2026-11-03 host: transports, LIODevice API and fault-injecting simulator
    - transport: SerialTransport (pyserial serial_for_url; DTR reset on
    open, line reads with timeouts, transcript), SimTransport on a
    virtual clock, USB VID/PID port discovery
    - device: LIODevice typed API for every protocol command; seq-number
    matching; events collected mid-command; per-command timeouts; host
    LED duty tracker that inserts and records cool-downs; context
    manager always sends OFF + MOTOR STOP on exit
    - sim: SimulatedLIO mirrors firmware v2 (safety rules, watchdog,
    comms failsafe, arming, legacy jogs) on a discrete-event virtual
    clock with baud-rate/ADC timing, and a physics-lite optical model
    (emitter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
2026-11-03 firmware: capture short ADC streams at the full ADC rate
    Each '# S' line takes about 3 ms at 115200 baud, so above about 250 SPS
    a live ADC STREAM was paced by the serial line, not the ADC (T03.4 and
    T07.1 need 860 SPS). Streams of up to STREAM_BUF_N = 48 samples are now
    captured into RAM first and printed afterwards; longer streams still
    print live. While waiting for TX buffer space the firmware keeps calling
    service(), so motors keep stepping during a stream (T09.4).
    SRAM 759 -> 1047 B (51 %), flash 22142 B (72 %), both bootloaders.
2026-11-03 host: simulate the serial TX buffer and buffered streams; device.send_raw
    - sim: Serial.print blocks while the 64-byte TX buffer is full, so live
    streams are paced by the line as on hardware; n <= stream_buf_n is
    captured first, matching the firmware.
    - device: send_raw() returns the first response of any sequence number
    (over-length and garbage lines are answered without @seq, T02.4).
    - device: ch_on() budgets the on-time the firmware will allow (request
    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
2026-11-03 host: run records, T11 verdict, and a sample-limited settling bound
    - lio.results: Status, SubResult, TestResult, RunRecord (results.json)
    and overall_verdict() implementing plan T11. Channel failures are
    attributed by the /hNN part of a sub-result id; 1-2 failing channels
    outside the expected-limited set count as DEGRADED (the plan leaves
    that case open).
    - analysis.settling: with fewer than 3 unsettled samples a first-order
    fit is noise; report the time of the first settled sample as an upper
    bound instead.
2026-11-03 tests: system test catalogue T01-T08, T10 and the fault-injection matrix
    lio.suite holds the catalogue as importable, typed functions (usable by
    pytest now and by 'lio selftest' in M5); tests/system maps each plan ID
    to one pytest function, marked sim and hw.
    - Shared measurements (dark stats, 16-channel matrix, polarity gate)
    are taken once on first use; every test also runs alone.
    - The runner restores the safe state after every test (retrying once on
    a lost line) and turns exceptions into ERROR results.
    - Unusable detectors (erratic, pinned, or InGaAs failing the hole-8
    polarity gate) are reported once in T06 and their later judgments are
    skipped instead of cascading.
    - test_faul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
2026-11-03 host: operator abstraction and gating for interactive and motion tests
    - lio.operator: ConsoleOperator (terminal prompts; 'a' aborts) and
    SimOperator, which answers from the simulator's physical truth: which
    LEDs really lit and in what order, whether a motor really turned, the
    rail current during a flash.
    - Runner: kind I needs an operator; kind M also needs --allow-motion. An
    abort is a SKIP after the usual safe-state restore. The simulator always
    has a simulated operator, so the whole catalogue runs in CI.
    - pytest: prompts work under output capture; --allow-motion implies an
    operator on hardware.
    - device.wait_for_duty(): cool down before the operator is told to watch.
    - confi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
2026-11-03 tests: T09 motors and the interactive steps T04.4, T05.6, T06.4
    - T09.1 arming (no ARM, wrong token, 60 s expiry with the link kept
    alive), T09.2 +/-64 half-steps per motor with the operator confirming
    direction (+ = up), T09.3 MOTOR STOP latency on a 2048-step move,
    T09.4 detector noise during a 256-step move. Every move is undone; the
    operator confirms the chamber is clear first.
    - T04.4 walk test, T05.6 driver current with a meter, T06.4 lid open /
    closed. Walk-test failures name holes, so they count as channel faults.
    - Fault matrix: motor_stall (T09.2), and swapped:3,4, which the detectors
    cannot see but the walk test can.
    - Verdict: the critical-module rule applies to autom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
2026-11-03 host: reports, sweep CSV, baselines; T08.4 and T11.1
    - lio.report: results.json, meas.csv (every MEAS/SWEEP), plots (channel
    response, response matrix, dark noise, step responses, repeated
    sweeps), report.md and report.html; rebuildable from results.json.
    Fixed per-detector colours (palette validated for CVD); status shown
    as icon + word, never colour alone.
    - lio.csvout: the original logger's CSV format, byte for byte; T08.4
    checks a live sweep against it.
    - lio.baseline: save a run to software/config/baseline_<date>.yaml
    (sample_id, firmware, config hash, per-channel values) and T11.1
    compares later runs (drift WARN 10 %, FAIL 25 %, provisional).
    - pytest writes the full repo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
2026-11-03 cli: the lio command line
    ports, info, status, ping, ch, off, meas, sweep (--csv/--plot), motor
    (one call arms, steps and waits; asks before moving unless -y), selftest
    (--modules by ID or name, --interactive, --allow-motion, --baseline,
    --save-baseline, metadata), report, shell and sim-serve. Exit codes:
    0 FUNCTIONAL, 1 DEGRADED, 2 NOT FUNCTIONAL, 3 error.
    Deviation: selftest runs the lio.suite catalogue directly rather than
    wrapping pytest, so the installed tool needs no test dependencies; the
    pytest entry point runs the same functions.
2026-11-03 logger: rewrite on lio.device; original kept in logger/legacy
    Same command line (python lio_logger.py PORT) and the same outputs
    (lio_sweep.csv byte-compatible, lio_sweep.png), now for firmware v2.
    The TEST_MODE 5 original is preserved unchanged in legacy/ behind a
    header (M0 approval 11).
2026-11-03 firmware, host: fixes from the hardware-readiness audit
    - adc: ads.begin() calls Wire.begin() again, which resets the bus to
    100 kHz; re-apply I2C_CLOCK_HZ (400 kHz) and the Wire timeout after it.
    At 100 kHz every conversion carried ~1.4 ms of I2C overhead (T03.4
    would fail at 860 SPS, every MEAS slower).
    - motors: no catch-up burst of fast steps after the loop was held up
    (e.g. printing INFO), which can stall a stepper.
    - device: I2C SCAN timeout from the YAML (6 s): on a stuck bus the scan
    takes 126 x 25 ms, longer than the old 3 s, so T03.1 would ERROR
    instead of FAIL with the wiring hint.
    - T09.1: compare failsafe_trips before/after, not against 0 since boot.
    - adc.conv_overh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
2026-11-03 docs: TESTING.md with the M6 checklist; READMEs, CHANGELOG; LIO-ELEC-001 proposal
    - docs/TESTING.md: set-up, everyday commands, running the whole system or
    any subsystem, the catalogue (what each test checks and catches), the
    verdict rules, deviations from the plan with reasons, known blind
    spots, reading failures, practising on the simulator, and the
    first-hardware-session checklist (bench, flashing both bootloaders,
    module order, baseline, calibration).
    - docs/proposals: proposed replacement text for LIO-ELEC-001 sections
    13-15 and the appendices (M0 decision 12). Not applied: the electronics
    documentation is unchanged.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
2026-11-03 Rename software/control/lio_control.py to lio_motor_control.py
    The name says what the script does (the Tkinter Z-axis jog controller).
    Contents unchanged.
2026-11-03 Remove superseded legacy software, update docs for lio_motor_control.py
    - Remove software/firmware/legacy/ (TEST_MODE firmware copy, old
    AccelStepper motor sketch) and software/logger/legacy/; both are kept at
    tag software-legacy-v1, and the TEST_MODE firmware/logger also at
    fw-testmode-v1. Drop the CI build step and ruff excludes for them.
    - Remove a stray CAD/creality_print_files/.DS_Store (no CAD changed).
    - Docs: refer to software/control/lio_motor_control.py; root README
    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
2026-11-03 device: request_cancel() stops the running test at its next command or wait
    One-shot and only when the device is marked cancellable, so the command
    line is unchanged and the safe-state restore after a stopped test works.
    run_test records a cancelled test as SKIP.
2026-11-03 dashboard: lio dashboard, a local web page with a digital twin
    Run any subsystem or the whole system from the browser, answer operator
    questions in the page, stop safely, Measure/Flash single holes. The twin
    colours the Nano, shift registers, rails, 16 holes, detectors, ADC, motors
    and safety logic by result; the overall T11 verdict covers the latest
    result of every test, with its coverage.
    Local only (127.0.0.1), every API call needs the page's token, Host header
    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
2026-11-03 Explain a missing boot banner; add environment.yml (conda env lio)
    - BootTimeout now says what the board sent instead of the firmware v2
    banner, or that it sent nothing, and that firmware v2 needs flashing.
    The dashboard shows it as a message instead of a server error.
    - environment.yml defines the lio conda environment (lio package in
    editable mode with the dev tools); docs use it instead of a .venv.
2026-11-03 tests: report what the pty bridge saw when a banner is missing
    The pty-bridge test still fails now and then on Linux CI with no banner,
    which does not reproduce on macOS. The bridge now records when it sees a
    client open or close and when it sends the banner; the test puts that
    trace in its failure message, which CI publishes as an annotation.
2026-11-03 Find the ADS1115 when power bank A wakes after boot
    The +5 V bus (ADS1115, LEDs, shift registers) comes only from power bank
    A. Firmware v2 releases the motor coils when idle, so the load is tiny and
    USB banks switch themselves off; the ADC then vanished from I2C, and the
    firmware only looked for it at boot. It now probes again whenever it is
    needed (INFO adc_ok, every ADC command) until it answers.
    T03.1's failure message and the docs now point first at bank A being
    asleep, with ways to keep both banks on.
2026-11-03 POWER WAKE: wake power bank A before tests and hardware commands
    USB power banks switch off at low load, and bank A alone powers the +5 V
    bus. POWER WAKE [ms] holds both motors' coils at their current phase (no
    steps, so nothing moves) for 1 s, then releases them. The host sends it
    when the port opens, before each test and before Measure/Flash, at most
    every power.interval_s; older firmware without it is detected and
    skipped. Simulator fault bank_a_asleep, healed by the wake (fault matrix).
    Also fixes the flaky pty-bridge test: the bridge now detects a client
    opening the port from the input flush pyserial does on open (pty packet
    mode), instead of waiting for Linux's 'no client' read error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
2026-11-03 dashboard: keep results between sessions; Wake bank A button
    The board is rebuilt from the saved runs in test_results/ when the
    dashboard starts or connects (hardware and simulator kept apart, latest
    result per test wins), so subsystem results persist between sessions.
    Each test shows the run it came from. Clear results is remembered in
    test_results/dashboard_state.json; reports are never deleted.
    A Wake bank A button holds the motor coils for 3 s (POWER WAKE, no
    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
2026-11-04 I2C DIAG: line-level SDA/SCL checks, 100 kHz fallback; T03.1 reports the bus
    Firmware 2.1.0 adds I2C DIAG (lines held low, external pull-ups, SDA-SCL
    bridge, ack at 100/400 kHz) and falls back to 100 kHz when only that
    works. T03.1 runs it and reports T03.1/bus with a diagnosis. Simulator
    faults i2c_bridged and i2c_slow, with fault-matrix rows.
2026-11-04 Software I2C on D11/D12: this Nano's A4/A5 are damaged (firmware 2.2.0)
    I2C DIAG and a meter found A4/A5 low with nothing attached. The ADS1115
    now runs over an open-drain software I2C bus on D11 (SDA) and D12 (SCL)
    with 4.7k pull-ups; a minimal ADS1115 driver replaces Adafruit ADS1X15,
    so the firmware needs no libraries. LOOP TEST reports not_fitted without
    touching D11. Pin map updated in lio_hw.yaml, the electronics docs (with
    approval) and the protocol; test hints read pin names from the config.
    T03.4 overhead allowance 1.5 ms (provisional).
2026-11-04 Software I2C: faster SCL edges; A4/A5 condition unconfirmed
    The SCL rise wait counted with micros() (~4 us per bit); 1 us steps cut the
    per-sample I2C overhead from ~2 ms to ~1.4 ms, and T03.4 passes on the
    hardware. The T03.1 failure was a loose VDD contact on the ADS1115 module,
    so the docs no longer call A4/A5 damaged. Open items: OPT101 output not
    reaching ADS A1; InGaAs output at 3.44 V dark.
2026-11-12 Firmware 2.3.1: Nano R4 (RA4M1) support; smooth repeated jogs
    The R4 has no DTR reset, so the firmware re-applies the dark state and
    prints "# BOOT" when the host opens the port. A jog repeated in the same
    direction renews its bound without restarting the speed ramp. The old
    ATmega328P Nano still builds.
2026-11-12 Food library: phone barcode app, product lookup, dashboard Database tab
    - lio.foods: barcode decoding, USDA FDC / NIH DSLD / openFDA / Open Food
    Facts lookups, web search fallback with source links, Apple Vision label
    reading, SQLite library with samples, photos and LIO scans.
    - Phone web app (iPhone and Android) served by the dashboard, reachable via
    a Cloudflare quick tunnel; pairing key on every call.
    - Dashboard Database tab: exports, add a sample, library viewer, inspector
    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
2026-11-12 Verifiable composition M4: independent verifier (lio-verify) and mutation tests
    - lio_verify.verify / cli: schema + no floats, source hashes, facts
    (locator, rule, interpretation), identities, derivations, constraints,
    bounds (exact witnesses + z3), attestations, assumptions; per-field
    VERIFIED / ATTESTED / UNVERIFIED / FAILED; fails closed; no network
    unless --refetch; imports nothing from lio or lio_comp.
    - Mutation tests for every spec §8 tamper case and more; all golden
    records pass.
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
